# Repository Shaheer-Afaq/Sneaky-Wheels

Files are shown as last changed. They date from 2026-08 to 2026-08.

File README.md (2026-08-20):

# Sneaky-Wheels
This is a remote controlled mini spy car designed in Onshape. I decided to build this because ive always wanted to drive an RC car with the car's POV. I like to watch and record remotely controlled terrain exploration. I finally got the chance to build this due to [Forge's](https://forge.hackclub.com.) funding program.

The 3d model of the casings is designed in Onshape:

[Onshape Document
](https://cad.onshape.com/documents/f87c3accc4a240ed7dab0743/w/c73ea29120acd2fcd4fea41f/e/9db8dd83f8640be167385dda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)

The wiring diagram (screenshot in the assembly section below) is made in EasyEDA. This is a hand-wired project.

## Bill of Materials:
| Component | Quantity | Price (USD) | Source |
|---|---|---|---|
| ESP32 NodeMCU | 2 | 8.3 | https://epro.pk/product/esp32-nodemcu-wifi-based-development-board/ |
| ESP32 Cam | 1 | 5.4 | https://epro.pk/product/esp32-cam-ov2640-board-in-pakistan/ |
| Esp32 Cam Mb Micro Usb Programmer Ch340g | 1 | 1.6 | https://epro.pk/product/esp32-cam-mb-micro-usb-programmer-ch340g-usb-to-serial-port-board/ |
| DC 12V N20 Metal Gear Motor | 4 | 2.5 | https://epro.pk/product/dc-12v-n20-metal-gear-motor-mini-for-smart-car-projects/ |
| Potentiometer Knob | 2 | 0.1 | https://epro.pk/product/potentiometer-knob-rotary-swirch-cap-ac120-in-pakistan/ |
| LED 5mm - White | 4 | 0.03 | https://epro.pk/product/led-5mm-super-bright-in-pakistan/?attribute_colors=White |
| 12V 2Amp Power Supply Adapter | 1 | 0.9 | https://epro.pk/product/12v-2amp-high-quality-power-supply-adapter/ |
| 10A 12V 3S BMS | 1 | 0.8 | https://epro.pk/product/10a-12v-lithium-battery-charger-module-bms-18650-in-pakistan/ |
| Type C TP4056 Li Charging Module 1A | 1 | 0.2 | https://epro.pk/product/tp4056-lithium-battery-charging-board-1a-type-c-in-pakistan/ |
| 18650 Battery Holder 1 Cell | 1 | 0.14 | https://epro.pk/product/18650-battery-holder-1-cell-in-pakistan/ |
| Potentiometer 10K | 2 | 0.22 | https://epro.pk/product/variable-resistor-potentiometer-volume-5k-10k-50k-100k/?attribute_value=10k |
| 3 Pin DC Power Jack | 1 | 0.054 | https://epro.pk/product/3-pin-dc-power-jack-pcb-mount-female-connector-in-pakistan/ |
| LM2596 Step Down Buck Converter | 1 | 0.65 | https://epro.pk/product/lm2596-dc-dc-adjustable-step-down-buck-converter/ |
| XL6009 DC to DC Boost Converter | 1 | 0.8 | https://epro.pk/product/https-epro-pk-product-xl6009-step-up-power-module-dc-dc-boost-converter-in-pakistan/ |
| Female Header 40 Pins | 3 | 0.5 | https://epro.pk/product/female-header-40-pins/ |
| 2 pin C3 Connector Male Header | 10 | 0.2 | https://epro.pk/product/2-pin-c3-connector-male-header-in-pakistan-per-piece/ |
| 2 Pin Molex Connector | 10 | 0.9 | https://epro.pk/product/2-pin-molex-connector-in-pakistan/ |
| 3 Pin Molex Connector | 2 | 0.22 | https://epro.pk/product/3-pin-molex-connector-in-pakistan/ |
| 6x8 Double Sided FR4 Veroboard | 2 | 1.8 | https://epro.pk/product/6x8-double-sided-fr4-veroboard-pcb-in-pakistan/ |
| Vero Board Jumper Wires | 1 | 1.4 | https://epro.pk/product/vero-board-breadboard-jumper-wires-red-black-color/ |
| Dual-axis XY Joystick Module KY-023 | 2 | 1 | https://epro.pk/product/dual-axis-xy-joystick-control-module-ky-023/ |
| TB6612 Dual Motor Driver Module | 1 | 2 | https://epro.pk/product/tb6612-drv8833-dual-motor-driver-module-1a-h-bridge-for-arduino-robotics/ |
| MPU6050 Analog Gyroscope Sensor 3 Axis | 1 | 1.8 | https://epro.pk/product/mpu6050-gy-521-3-axis-analog-gyroscope-sensor-in-pakistan/ |
| 0.8mm 2.5ft Soldering Wire | 2 | 0.22 | https://epro.pk/product/0-8mm-2-5ft-soldering-wire-in-pakistan/ |
| 18650 Li-ion Battery Cell | 4 | 4.3 | https://epro.pk/product/inr18650-li-ion-lithium-battery-cell-3-7v-high-capacity-power-cell/ |
| Push Button Switch SMD | 4 | 0.2 | https://epro.pk/product/push-button-switch-smd/ |
| Female to Female Jumper Wires 20cm | 1 | 0.7 | https://epro.pk/product/female-to-female-jumper-wires-30cm-40-pin-in-pakistan/ |
| 2.5mm Male Header Pins - 40 Pins | 1 | 0.07 | https://epro.pk/product/male-header-pins-40-pins/ |
| 25v 1000 uF Electrolytic Capacitor | 2 | 0.18 | https://epro.pk/product/radial-electrolytic-1000uf-capacitor-in-pakistan/?attribute_voltage=25V |
| C1815 Transistor NPN | 2 | 0.0036 | https://epro.pk/product/c1815-transistor-npn-transistor-price-in-pakistan/ |
| 3mm Heat Shrink Tube | 1 | 0.1 | https://epro.pk/product/16mm-to-20mm-heat-shrink-tube-shrinkable-tubing-cable-sleeve-wrap-wire-meter-in-pakistan/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 |
| 7mm Heat Shrink Tube | 1 | 0.13 | https://epro.pk/product/16mm-to-20mm-heat-shrink-tube-shrinkable-tubing-cable-sleeve-wrap-wire-meter-in-pakistan/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 |
| 20pcs 1/4W 1k ohm resistor | 1 | 0.81 | https://www.daraz.pk//products/i286672446-s1545954955.html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 |
| 20pcs 1/4W 100 ohm resistor | 1 | 0.83 | https://www.daraz.pk//products/i102804008-s1248682627.html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 |
| Car Wheel 43mm for N20 DC Gear Motor | 4 | 4.5 | https://www.daraz.pk//products/i17559537-s329887429.html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 |
| Soldering Tip | 1 | 1.26 | https://epro.pk/product/tni-u-soldering-iron-k-type-bit-60w/ |
| M2 screws | 18 | 0.25 | https://www.daraz.pk/products/m2-m25-m3-250500pcs-i1954210452.html?spm=a2a0e.searchlist.list.1.593733c5KpRiYM or any local hardware store |
| 3D Prints | - | 10 | https://printlegion.hackclub.com/ |
| | Total | 56 | |
                                                                                  |

## Car Assembly

1. Solder wires to motors with 2-pin molex connectors.

2. Build a 3S battery by soldering the wires on the bms, (circuit shown in the schematic below)

3. Solder wires to the bms, power jack, buck converter and push button according to the schematic. Solder wires on the output of the buck converter with a 2-pin female connector

4. Fix the motors in their slots in the corners and use super glue to fix them if they are loose.

5. Solder wires to the second push button, LEDs and GND and 5V of ESP-CAM with 2pin connectors on the end

6. Fix the push buttons, power jack, LEDs and ESP-CAM in their respective slots as shown in the model.

7. Use double-sided tape to stick the battery on the bottom and the bms on the side of the battery as shown.

8. Cut a protoboard according to the dimensions shown in the top view of the car model.

9. Solder female header pins for esp32 and motor driver as shown in the top-view.

10. Solder male molex connectors on the protoboard for the motors, LEDs and one push button, anywhere on the empty space (make sure to optimize the positions according to the schematic). And solder other components like the transistor circuit, and capacitor as shown in the schematic.

11. Use screws to fix the protoboard. Plugin the esp32 and motor driver, and stick the buck converter with double sided tape.

13. Slide in the lid and screw-in M2 screws from the holes in the sides.

14. Put the wheels on each motor.

---


---





### Top


### Rear


### Side


### Front


## Remote Assembly

1. Solder wires on potentiometers with 3pin connectors and push buttons with 2pin connectors on the ends.

2. Solder wires on tp4056 and cellholder. Stick cellholder with double-sided tape.

3. Solder the output of tp4056 to the input of XL6009 and a 2pin connector to the output of XL6009.

3. Cut out a protoboard and solder female pin headers for esp32 and mpu6050, as shown in the top-view below.

4. Put female-female jumper wires on the joysticks and use M2 screws to secure them into place.

5. Fix the potentiometers, push buttons, tp-4506 and XL6009 in their respective slots and glue them as needed.

6. Solder other parts of connector pairs (male holder for each) on the protoboard, optimizing the position according to the schematic.

7. Secure the protoboard with a M2 screw and plugin the esp32 and mpu6050.

8. Secure the lid with 4 M2 screws, then put the joystick heads and potentiometer knobs (cut the knobs short).

---


---




### Top


### Sides 


<br>


---

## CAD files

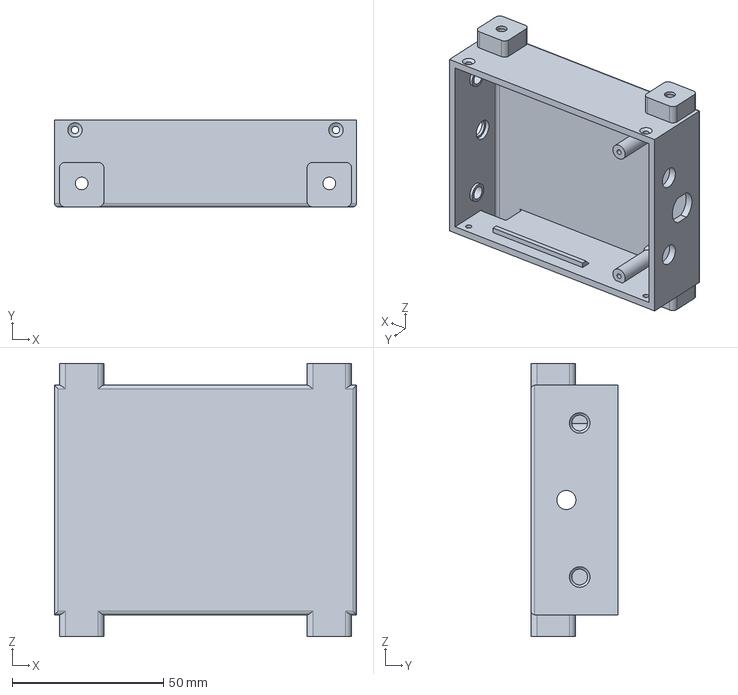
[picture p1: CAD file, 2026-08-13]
Car models/Car - Body.step
100.0 x 28.8 x 90.4 mm

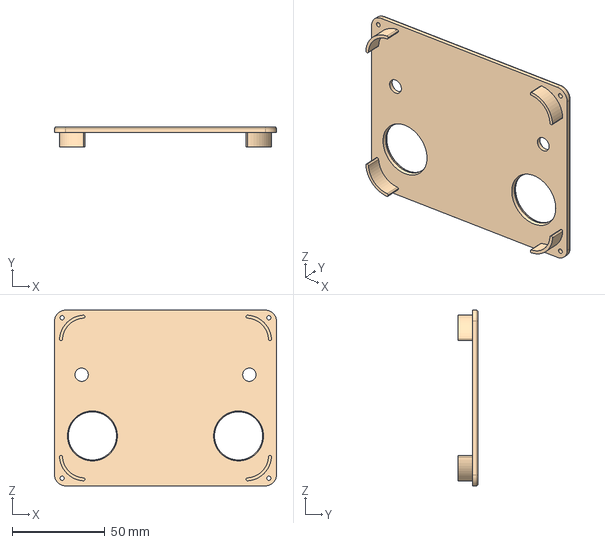
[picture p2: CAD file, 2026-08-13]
Remote models/Remote - Lid.step
120.0 x 11.0 x 95.0 mm

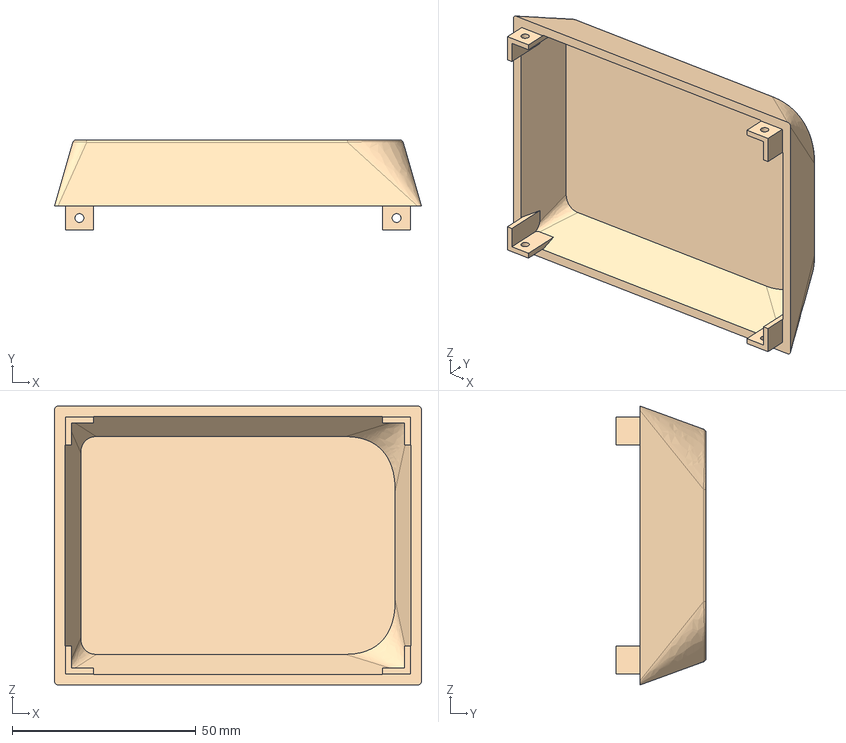
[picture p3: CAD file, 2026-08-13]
Car models/Car - Lid.step
100.0 x 24.6 x 76.0 mm

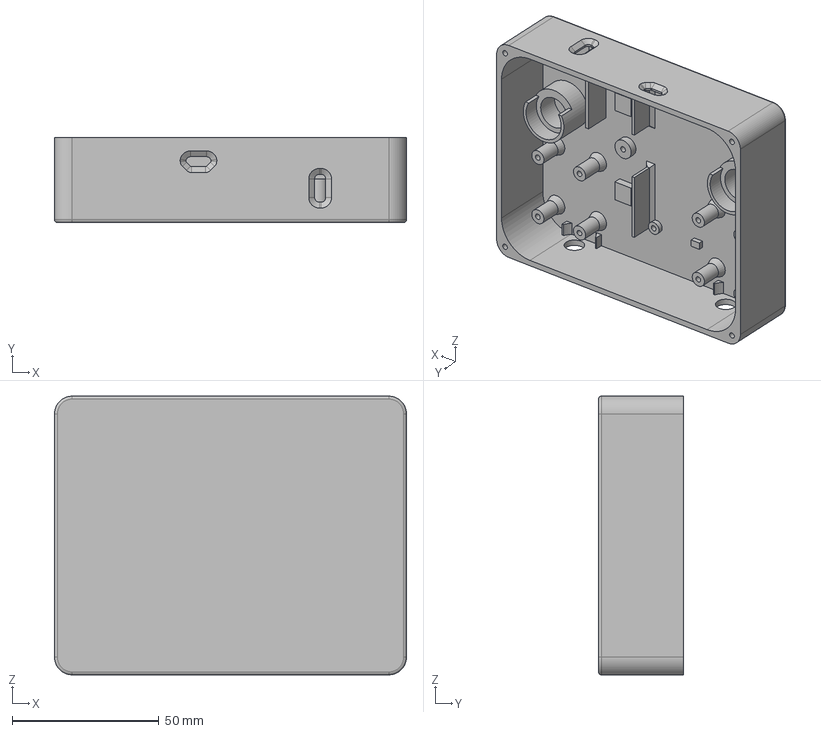
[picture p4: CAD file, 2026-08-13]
Remote models/Remote - Body.step
120.0 x 29.0 x 95.0 mm

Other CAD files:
Car models/Car - Body.stl
Car models/Car - Lid.stl
Remote models/Remote - Body.stl
Remote models/Remote - Lid.stl

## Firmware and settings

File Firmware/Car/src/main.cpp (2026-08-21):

// Run this first to get the MAC address of the ESP32
/*
#include "WiFi.h"

void setup() {

  // Setup Serial Monitor
  Serial.begin(115200);

  // Put ESP32 into Station mode
  WiFi.mode(WIFI_MODE_STA);

  // Print MAC Address to Serial monitor
  Serial.print("MAC Address: ");
  Serial.println(WiFi.macAddress());
}

void loop() {

}
*/

#include <WiFi.h>
#include <esp_now.h>
#include <esp_wifi.h>

#define motorA1 12
#define motorA2 13
#define motorAS 14

#define motorB1 26
#define motorB2 27
#define motorBS 25

#define headlight 23

struct data {
   int16_t x1; // joystick 1 x-axis
   int16_t y1; // joystick 1 y-axis
   boolean b1; // joystick 1 button
   int16_t x2; // joystick 2 x-axis
   int16_t y2; // joystick 2 y-axis
   boolean b2; // joystick 2 button
   int16_t p1; // potentiometer 1
   int16_t p2; // potentiometer 2
   boolean b3; // button
   int16_t aX; // angle x
   int16_t aY; // angle y
   int16_t aZ; // angle z
};

data myData;

bool lightButtonWasPressed = false;
bool lightOn = false;
unsigned long lastPacketTime = 0;
int sensitivity = 30;

void OnDataRecv(const uint8_t *mac, const uint8_t *incomingData, int len);
void driveRightMotor(int speed);
void driveLeftMotor(int speed);

void setup() {
   Serial.begin(115200);

   pinMode(motorA1, OUTPUT);
   pinMode(motorA2, OUTPUT);
   pinMode(motorAS, OUTPUT);
   pinMode(motorB1, OUTPUT);
   pinMode(motorB2, OUTPUT);
   pinMode(motorBS, OUTPUT);
   pinMode(headlight, OUTPUT);

   WiFi.mode(WIFI_STA);
   esp_wifi_set_channel(1, WIFI_SECOND_CHAN_NONE);

   if (esp_now_init() != ESP_OK) {
      Serial.println("Error initializing ESP-NOW");
      return;
   }
   esp_now_register_recv_cb(OnDataRecv);
}

void loop() {
   // stop the car if the connection is lost for more than 300ms
   if (millis() - lastPacketTime > 300) {
      driveRightMotor(0);
      driveLeftMotor(0);
      digitalWrite(headlight, LOW);
      return;
   }

   sensitivity = map(myData.p1, 0, 4095, 30, 90);

   int throttle, steering;
   if (myData.b1) { // if gyro mode is enabled
      throttle = constrain(map(myData.aX, -sensitivity, sensitivity, -255, 255), -255, 255);
      steering = constrain(map(myData.aY, -sensitivity, sensitivity, -255, 255), -255, 255);
   } else {
      throttle = map(myData.y1, 0, 4095, -255, 255);
      steering = map(myData.x2, 0, 4095, -255, 255);
   }

   int rightSpeed, leftSpeed;
   if (abs(throttle) < 20) { // for spinning in place
      rightSpeed = -steering;
      leftSpeed = steering;
   } else {
      rightSpeed = throttle;
      leftSpeed = throttle;
      // to reduce the speed of one motor based on steering strength and direction
      if (steering > 20) rightSpeed = throttle * (255 - steering) / 255;
      else if (steering < -20) leftSpeed = throttle * (255 + steering) / 255;
   }
   driveRightMotor(rightSpeed);
   driveLeftMotor(leftSpeed);

   // toggle headlight
   if (myData.b3) lightButtonWasPressed = true;

   if (lightButtonWasPressed && !myData.b3) {
      lightOn = !lightOn;
      lightButtonWasPressed = false;
      digitalWrite(headlight, lightOn);
   }
}

void OnDataRecv(const uint8_t *mac, const uint8_t *incomingData, int len) {
   if (len == sizeof(myData)) {
      memcpy(&myData, incomingData, sizeof(myData));
      lastPacketTime = millis();
   }
}

void driveRightMotor(int speed) {
   if (speed > 0) {
      digitalWrite(motorA1, HIGH);
      digitalWrite(motorA2, LOW);
   } else if (speed < 0) {
      digitalWrite(motorA1, LOW);
      digitalWrite(motorA2, HIGH);
   } else {
      digitalWrite(motorA1, LOW);
      digitalWrite(motorA2, LOW);
   }
   analogWrite(motorAS, abs(speed));
}

void driveLeftMotor(int speed) {
   if (speed > 0) {
      digitalWrite(motorB1, HIGH);
      digitalWrite(motorB2, LOW);
   } else if (speed < 0) {
      digitalWrite(motorB1, LOW);
      digitalWrite(motorB2, HIGH);
   } else {
      digitalWrite(motorB1, LOW);
      digitalWrite(motorB2, LOW);
   }
   analogWrite(motorBS, abs(speed));
}

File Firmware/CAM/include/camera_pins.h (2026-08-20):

#if defined(CAMERA_MODEL_WROVER_KIT)
#define PWDN_GPIO_NUM  -1
#define RESET_GPIO_NUM -1
#define XCLK_GPIO_NUM  21
#define SIOD_GPIO_NUM  26
#define SIOC_GPIO_NUM  27

#define Y9_GPIO_NUM    35
#define Y8_GPIO_NUM    34
#define Y7_GPIO_NUM    39
#define Y6_GPIO_NUM    36
#define Y5_GPIO_NUM    19
#define Y4_GPIO_NUM    18
#define Y3_GPIO_NUM    5
#define Y2_GPIO_NUM    4
#define VSYNC_GPIO_NUM 25
#define HREF_GPIO_NUM  23
#define PCLK_GPIO_NUM  22

#elif defined(CAMERA_MODEL_ESP_EYE)
#define PWDN_GPIO_NUM  -1
#define RESET_GPIO_NUM -1
#define XCLK_GPIO_NUM  4
#define SIOD_GPIO_NUM  18
#define SIOC_GPIO_NUM  23

#define Y9_GPIO_NUM    36
#define Y8_GPIO_NUM    37
#define Y7_GPIO_NUM    38
#define Y6_GPIO_NUM    39
#define Y5_GPIO_NUM    35
#define Y4_GPIO_NUM    14
#define Y3_GPIO_NUM    13
#define Y2_GPIO_NUM    34
#define VSYNC_GPIO_NUM 5
#define HREF_GPIO_NUM  27
#define PCLK_GPIO_NUM  25

#define LED_GPIO_NUM 22

#elif defined(CAMERA_MODEL_M5STACK_PSRAM)
#define PWDN_GPIO_NUM  -1
#define RESET_GPIO_NUM 15
#define XCLK_GPIO_NUM  27
#define SIOD_GPIO_NUM  25
#define SIOC_GPIO_NUM  23

#define Y9_GPIO_NUM    19
#define Y8_GPIO_NUM    36
#define Y7_GPIO_NUM    18
#define Y6_GPIO_NUM    39
#define Y5_GPIO_NUM    5
#define Y4_GPIO_NUM    34
#define Y3_GPIO_NUM    35
#define Y2_GPIO_NUM    32
#define VSYNC_GPIO_NUM 22
#define HREF_GPIO_NUM  26
#define PCLK_GPIO_NUM  21

#elif defined(CAMERA_MODEL_M5STACK_V2_PSRAM)
#define PWDN_GPIO_NUM  -1
#define RESET_GPIO_NUM 15
#define XCLK_GPIO_NUM  27
#define SIOD_GPIO_NUM  22
#define SIOC_GPIO_NUM  23

#define Y9_GPIO_NUM    19
#define Y8_GPIO_NUM    36
#define Y7_GPIO_NUM    18
#define Y6_GPIO_NUM    39
#define Y5_GPIO_NUM    5
#define Y4_GPIO_NUM    34
#define Y3_GPIO_NUM    35
#define Y2_GPIO_NUM    32
#define VSYNC_GPIO_NUM 25
#define HREF_GPIO_NUM  26
#define PCLK_GPIO_NUM  21

#elif defined(CAMERA_MODEL_M5STACK_WIDE)
#define PWDN_GPIO_NUM  -1
#define RESET_GPIO_NUM 15
#define XCLK_GPIO_NUM  27
#define SIOD_GPIO_NUM  22
#define SIOC_GPIO_NUM  23

#define Y9_GPIO_NUM    19
#define Y8_GPIO_NUM    36
#define Y7_GPIO_NUM    18
#define Y6_GPIO_NUM    39
#define Y5_GPIO_NUM    5
#define Y4_GPIO_NUM    34
#define Y3_GPIO_NUM    35
#define Y2_GPIO_NUM    32
#define VSYNC_GPIO_NUM 25
#define HREF_GPIO_NUM  26
#define PCLK_GPIO_NUM  21

#define LED_GPIO_NUM 2

#elif defined(CAMERA_MODEL_M5STACK_ESP32CAM)
#define PWDN_GPIO_NUM  -1
#define RESET_GPIO_NUM 15
#define XCLK_GPIO_NUM  27
#define SIOD_GPIO_NUM  25
#define SIOC_GPIO_NUM  23

#define Y9_GPIO_NUM    19
#define Y8_GPIO_NUM    36
#define Y7_GPIO_NUM    18
#define Y6_GPIO_NUM    39
#define Y5_GPIO_NUM    5
#define Y4_GPIO_NUM    34
#define Y3_GPIO_NUM    35
#define Y2_GPIO_NUM    17
#define VSYNC_GPIO_NUM 22
#define HREF_GPIO_NUM  26
#define PCLK_GPIO_NUM  21

#elif defined(CAMERA_MODEL_M5STACK_UNITCAM)
#define PWDN_GPIO_NUM  -1
#define RESET_GPIO_NUM 15
#define XCLK_GPIO_NUM  27
#define SIOD_GPIO_NUM  25
#define SIOC_GPIO_NUM  23

#define Y9_GPIO_NUM    19
#define Y8_GPIO_NUM    36
#define Y7_GPIO_NUM    18
#define Y6_GPIO_NUM    39
#define Y5_GPIO_NUM    5
#define Y4_GPIO_NUM    34
#define Y3_GPIO_NUM    35
#define Y2_GPIO_NUM    32
#define VSYNC_GPIO_NUM 22
#define HREF_GPIO_NUM  26
#define PCLK_GPIO_NUM  21

#elif defined(CAMERA_MODEL_M5STACK_CAMS3_UNIT)
#define PWDN_GPIO_NUM  -1
#define RESET_GPIO_NUM 21
#define XCLK_GPIO_NUM  11
#define SIOD_GPIO_NUM  17
#define SIOC_GPIO_NUM  41

#define Y9_GPIO_NUM    13
#define Y8_GPIO_NUM    4
#define Y7_GPIO_NUM    10
#define Y6_GPIO_NUM    5
#define Y5_GPIO_NUM    7
#define Y4_GPIO_NUM    16
#define Y3_GPIO_NUM    15
#define Y2_GPIO_NUM    6
#define VSYNC_GPIO_NUM 42
#define HREF_GPIO_NUM  18
#define PCLK_GPIO_NUM  12

#define LED_GPIO_NUM 14

#elif defined(CAMERA_MODEL_AI_THINKER)
#define PWDN_GPIO_NUM  32
#define RESET_GPIO_NUM -1
#define XCLK_GPIO_NUM  0
#define SIOD_GPIO_NUM  26
#define SIOC_GPIO_NUM  27

#define Y9_GPIO_NUM    35
#define Y8_GPIO_NUM    34
#define Y7_GPIO_NUM    39
#define Y6_GPIO_NUM    36
#define Y5_GPIO_NUM    21
#define Y4_GPIO_NUM    19
#define Y3_GPIO_NUM    18
#define Y2_GPIO_NUM    5
#define VSYNC_GPIO_NUM 25
#define HREF_GPIO_NUM  23
#define PCLK_GPIO_NUM  22

// 4 for flash led or 33 for normal led
// #define LED_GPIO_NUM   4

#elif defined(CAMERA_MODEL_TTGO_T_JOURNAL)
#define PWDN_GPIO_NUM  0
#define RESET_GPIO_NUM 15
#define XCLK_GPIO_NUM  27
#define SIOD_GPIO_NUM  25
#define SIOC_GPIO_NUM  23

#define Y9_GPIO_NUM    19
#define Y8_GPIO_NUM    36
#define Y7_GPIO_NUM    18
#define Y6_GPIO_NUM    39
#define Y5_GPIO_NUM    5
#define Y4_GPIO_NUM    34
#define Y3_GPIO_NUM    35
#define Y2_GPIO_NUM    17
#define VSYNC_GPIO_NUM 22
#define HREF_GPIO_NUM  26
#define PCLK_GPIO_NUM  21

#elif defined(CAMERA_MODEL_XIAO_ESP32S3)
#define PWDN_GPIO_NUM  -1
#define RESET_GPIO_NUM -1
#define XCLK_GPIO_NUM  10
#define SIOD_GPIO_NUM  40
#define SIOC_GPIO_NUM  39
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

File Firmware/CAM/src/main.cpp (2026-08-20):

#include <Arduino.h>
#include "esp_camera.h"
#include <WiFi.h>

// ===========================
// Select camera model in board_config.h
// ===========================
#include "board_config.h"

// ===========================
// Enter your WiFi credentials
// ===========================
const char *ssid = "espcam";
const char *password = "espcam123";

void startCameraServer();
void setupLedFlash();

void setup() {
  Serial.begin(115200);
  Serial.setDebugOutput(true);
  Serial.println();

  camera_config_t config;
  config.ledc_channel = LEDC_CHANNEL_0;
  config.ledc_timer = LEDC_TIMER_0;
  config.pin_d0 = Y2_GPIO_NUM;
  config.pin_d1 = Y3_GPIO_NUM;
  config.pin_d2 = Y4_GPIO_NUM;
  config.pin_d3 = Y5_GPIO_NUM;
  config.pin_d4 = Y6_GPIO_NUM;
  config.pin_d5 = Y7_GPIO_NUM;
  config.pin_d6 = Y8_GPIO_NUM;
  config.pin_d7 = Y9_GPIO_NUM;
  config.pin_xclk = XCLK_GPIO_NUM;
  config.pin_pclk = PCLK_GPIO_NUM;
  config.pin_vsync = VSYNC_GPIO_NUM;
  config.pin_href = HREF_GPIO_NUM;
  config.pin_sccb_sda = SIOD_GPIO_NUM;
  config.pin_sccb_scl = SIOC_GPIO_NUM;
  config.pin_pwdn = PWDN_GPIO_NUM;
  config.pin_reset = RESET_GPIO_NUM;
  config.xclk_freq_hz = 20000000;
  config.frame_size = FRAMESIZE_UXGA;
  config.pixel_format = PIXFORMAT_JPEG;  // for streaming
  //config.pixel_format = PIXFORMAT_RGB565; // for face detection/recognition
  config.grab_mode = CAMERA_GRAB_WHEN_EMPTY;
  config.fb_location = CAMERA_FB_IN_PSRAM;
  config.jpeg_quality = 12;
  config.fb_count = 1;

  // if PSRAM IC present, init with UXGA resolution and higher JPEG quality
  //                      for larger pre-allocated frame buffer.
  if (config.pixel_format == PIXFORMAT_JPEG) {
    if (psramFound()) {
      config.jpeg_quality = 10;
      config.fb_count = 2;
      config.grab_mode = CAMERA_GRAB_LATEST;
    } else {
      // Limit the frame size when PSRAM is not available
      config.frame_size = FRAMESIZE_SVGA;
      config.fb_location = CAMERA_FB_IN_DRAM;
    }
  } else {
    // Best option for face detection/recognition
    config.frame_size = FRAMESIZE_240X240;
#if CONFIG_IDF_TARGET_ESP32S3
    config.fb_count = 2;
#endif
  }

#if defined(CAMERA_MODEL_ESP_EYE)
  pinMode(13, INPUT_PULLUP);
  pinMode(14, INPUT_PULLUP);
#endif

  // camera init
  esp_err_t err = esp_camera_init(&config);
  if (err != ESP_OK) {
    Serial.printf("Camera init failed with error 0x%x", err);
    return;
  }

  sensor_t *s = esp_camera_sensor_get();
  // initial sensors are flipped vertically and colors are a bit saturated
  if (s->id.PID == OV3660_PID) {
    s->set_vflip(s, 1);        // flip it back
    s->set_brightness(s, 1);   // up the brightness just a bit
    s->set_saturation(s, -2);  // lower the saturation
  }
  // drop down frame size for higher initial frame rate
  if (config.pixel_format == PIXFORMAT_JPEG) {
    s->set_framesize(s, FRAMESIZE_QVGA);
  }

#if defined(CAMERA_MODEL_M5STACK_WIDE) || defined(CAMERA_MODEL_M5STACK_ESP32CAM)
  s->set_vflip(s, 1);
  s->set_hmirror(s, 1);
#endif

#if defined(CAMERA_MODEL_ESP32S3_EYE)
  s->set_vflip(s, 1);
#endif

// Setup LED FLash if LED pin is defined in camera_pins.h
#if defined(LED_GPIO_NUM)
  setupLedFlash();
#endif

  WiFi.softAP(ssid);
  WiFi.setSleep(false);

  Serial.println("");
  Serial.println("WiFi AP started");

  startCameraServer();

  Serial.print("Camera Ready! Use 'http://");
  Serial.print(WiFi.softAPIP());
  Serial.println("' to connect");
}

void loop() {
  delay(10000);
}

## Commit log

2026-06-07 Uploaded step files for the casings
    [Car - Body.step, Car - Lid.step, Remote - Body.step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]
2026-06-19 added stl files
    [Car - Body.stl, Car - Lid.stl, Remote - Body.stl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]
2026-06-19 edited readme
    Added information about PCB components and their assembly.
2026-06-23 added 3d models of assembly
2026-06-25 updated component list, added detailed assembly instructions
2026-06-25 added schematic
2026-06-25 edited car schematic
2026-06-25 mentioned that this is a hand-wired project in readme
2026-07-10 added BOM.csv and BOM in Readme
    [BOM.csv, Car - Body.step, Car - Body.stl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]
2026-08-13 added XL6009 boost converter to BOM
    [BOM.csv]
2026-08-13 updated model files
    [Car - Body.step, Car - Body.stl, Car - Lid.step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]
2026-08-13 added 3d printing costs to BOM
    [BOM.csv]
2026-08-15 changed BOM to USD
    [BOM.csv]
2026-08-19 added esp-cam code
    [partitions.csv]
2026-08-20 edited assembly instructions in readme
2026-08-20 removed led flash in espcam and added pin definition and motor drive functions to car
2026-08-21 gyro, fail-safe
2026-08-31 updated remote lid files for print optimization
2026-09-06 updated car models for print optimization
2026-09-06 updated car lid for print optimization
2026-10-27 updated schematic source file
